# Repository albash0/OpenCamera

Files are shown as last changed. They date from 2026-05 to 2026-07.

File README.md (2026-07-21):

# OpenCamera

An open-source, mostly 3D-printed 35 mm SLR film-camera prototype controlled by an ESP32-C3.

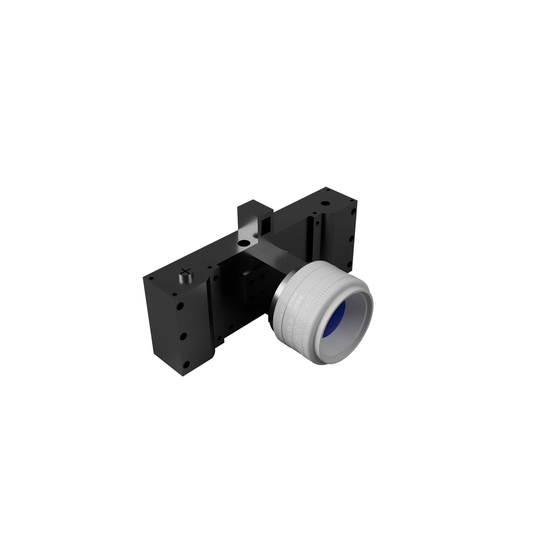
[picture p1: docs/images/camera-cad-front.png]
OpenCamera V71 CAD render


OpenCamera combines a manual 35 mm film transport with three electronically controlled systems:

- a small servo raises and lowers the SLR mirror;
- an 8520 coreless DC motor drives a rack-and-pinion shutter;
- a slot-type infrared sensor measures the shutter sweep so the ESP32-C3 can calculate the effective exposure time.

This guide describes the current **V71 prototype** represented by the CAD assembly, capstone presentation, and firmware in this repository.

> [!IMPORTANT]
> OpenCamera is a working prototype, not yet a turnkey camera kit. The repository contains one STEP assembly and working controller firmware, but it does not yet include individual STL files, a circuit schematic, a finalized PCB, a fastener list, validated slicer settings, or a film-advance counter. Expect to separate the CAD assembly into printable parts, measure hardware, adjust fits, and calibrate your build.

## Project files

| File | Purpose |
| --- | --- |
| [`camera v71.step`](camera%20v71.step) | Complete V71 mechanical assembly, including the body, film canister and roller, manual winder, mirror assembly, Canon FD flange, and servo hardware |
| [`OpenCamera_Firmware/firmware.ino`](OpenCamera_Firmware/firmware.ino) | ESP32-C3 shutter, mirror, sensor, OLED, and button controller |
| [`Capstone Presentation.pptx`](Capstone%20Presentation.pptx) | Design history, prototype photos, subsystem descriptions, and test results |

## Before you build

The current design makes several deliberate simplifications:

- **Film advance is manual.** An earlier geared-stepper design was abandoned because its electronics were too difficult to debug within the project timeline.
- **Electronics are built on protoboard.** A custom PCB was explored, but the current direct-I/O firmware no longer needs the earlier stepper circuitry.
- **The shutter has no home or end-position switch.** The firmware assumes the shutter starts at the correct end and toggles its direction flag after every trigger—even one that times out.
- **Light sealing and focus require hand fitting.** Prototype testing identified light leaks and focal-flange distance as the two main mechanical challenges.
- **The lux sensor described in the presentation is not implemented in the current firmware.** Exposure is adjusted manually by changing motor PWM.

<p align="center">
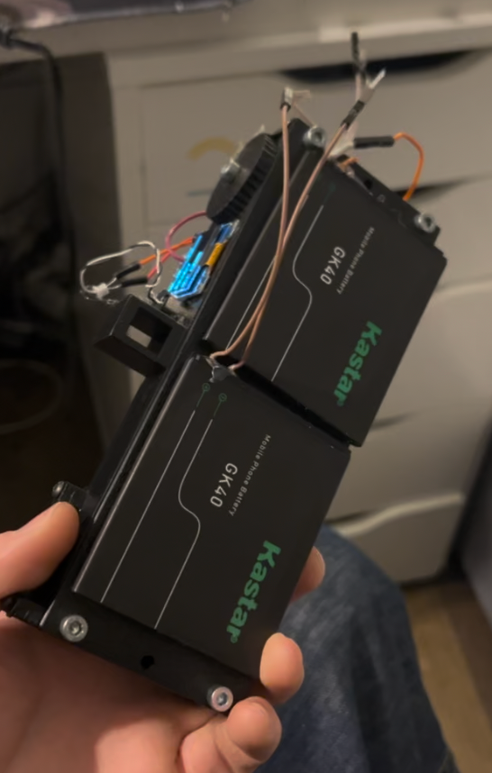
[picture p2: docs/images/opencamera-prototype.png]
OpenCamera physical prototype held in one hand
  
</p>

## How one exposure works

1. Pressing the trigger pulls its ESP32 input to ground.
2. The mirror servo moves from `40°` (viewing position) to `75°` (exposure position), then waits 250 ms.
3. The TB6612FNG drives the shutter motor at the selected PWM value. The default is `185` on a `0–255` scale.
4. The controller waits for the IR sensor to change from HIGH to LOW, records `t1`, then waits for it to return HIGH and records `t2`.
5. The motor stops, the exposure time is calculated, and the result is shown on the OLED and printed over USB serial.
6. The mirror returns to `40°`. After the exposure routine exits, the firmware toggles the direction for the next trigger.

The mirror, shutter, and sensor must all work on the bench before film is loaded.

## Parts

### Mechanical and optical parts

| Part | Notes |
| --- | --- |
| Printed V71 camera parts | Export the required bodies from the STEP assembly. The presentation recommends opaque ABS because it is durable and light resistant. |
| 35 mm film canister and take-up roller | Both are represented in the CAD assembly. The current take-up/advance mechanism is manual. |
| Canon FD lens and compatible flange | The V71 assembly includes a component named `Bague_CanonFD`. Verify focus on your printed body before exposing film. |
| Shutter panel/carriage, rack, and pinion | The shutter is designed as a removable module that screws into the camera body. |
| Laser-cut acrylic mirror | Mounted to the mirror mechanism and moved by a mini servo. A first-surface mirror will avoid the double image produced by ordinary back-silvered mirror material. |
| Translucent laminate or focusing-screen material | Mounted above the mirror so the reflected image can be viewed. |
| Light-sealing material | Opaque foam, flocking, paint, tape, or another suitable material for closing seams after fitting. |
| Shafts, screws, and small hardware | Sizes are not documented separately; inspect and measure the holes in the STEP assembly before ordering. |

### Electronics

| Part | Role |
| --- | --- |
| ESP32-C3 development board | Runs the firmware. Use a board that exposes every GPIO listed in the wiring table below. |
| TB6612FNG dual H-bridge module | Controls shutter-motor speed and direction using channel A. |
| 8520 coreless DC motor | Drives the rack-and-pinion shutter. Match its rated voltage when choosing the motor supply. |
| Slot-type IR sensor | Produces the two timing edges used to measure the shutter sweep. |
| Small RC servo | Moves the mirror. The presentation/CAD uses a mini 2 g servo; the mount may need adaptation for another servo. |
| 128×64 SSD1306 I²C OLED | Optional status display at address `0x3C`; the camera can still report over serial if it is absent. |
| 3 normally-open momentary buttons | Trigger, speed up, and speed down. The firmware uses internal pull-ups. |
| Prototyping board and hookup wire | Matches the current prototype electronics approach. |
| Suitable regulated power supplies | Size the logic, motor, and servo supplies for the actual components. Join their grounds. Never power a motor or servo from a GPIO pin. |

The presentation also mentions a boost converter, but the repository does not document the final power circuit or supply voltages. Design the power system around the ratings of your chosen board, motor, servo, sensor, and display.

### Tools and software

- a CAD program that can open STEP assemblies and export individual bodies;
- a slicer and 3D printer;
- a laser cutter or another safe method of cutting the mirror;
- soldering tools, wire cutters, and a multimeter;
- calipers for checking the film path, shutter feature, and optical spacing;
- Arduino IDE or another Arduino-compatible ESP32 build environment;
- a sacrificial or already-developed strip of 35 mm film for transport testing.

## Build guide

### 1. Inspect and separate the CAD assembly

Open [`camera v71.step`](camera%20v71.step) in your CAD program and inspect the complete mechanism before exporting anything. The assembly contains named components for the camera body, test housing, film canister, winder, film-can roller, mirror assembly, light-tight insert, Canon FD flange, and mini servo hardware.

Export only printable camera components as individual STL or 3MF files. Do not export vendor models such as the servo as printable parts. Preserve the STEP file's millimetre scale and check at least one known part before slicing.

The design is modular: the shutter is a separate unit that mounts inside the body. Keep that interface intact so the shutter can be removed for adjustment.

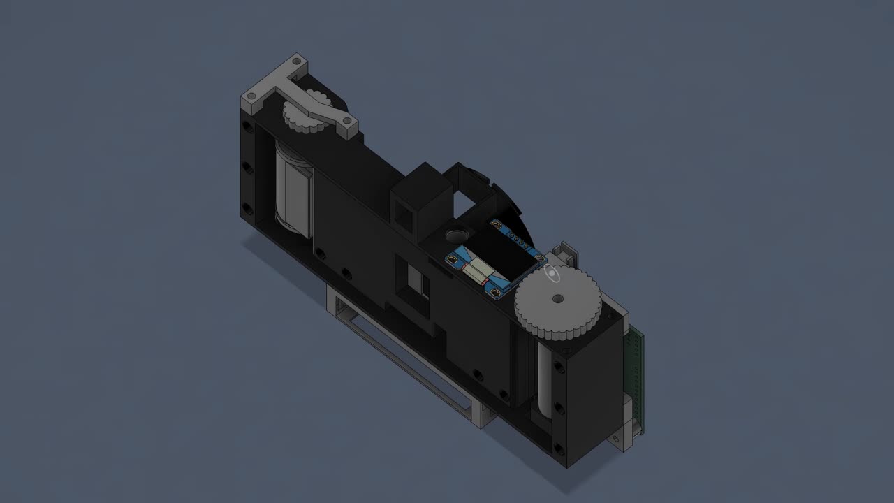
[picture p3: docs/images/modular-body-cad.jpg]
CAD render of the modular body, film path, and shutter assembly


### 2. Print and prepare the camera parts

The original build used ABS for opacity, durability, and longevity. If you use another material, hold a strong flashlight behind a test print in a dark room; a print that looks black in daylight may still leak light.

There are no validated print settings in the repository. Use the CAD geometry to choose orientation and supports, then dry-fit every moving part before final assembly. Clean the following areas carefully:

- the film rails and canister/roller pockets;
- the shutter-carriage guide and rack;
- the motor, servo, sensor, and lens-flange mounts;
- the removable shutter-module screw holes;
- the rear-cover seam and all openings into the film chamber.

Nothing in the film path should scratch emulsion, and the shutter must travel freely without binding.

### 3. Assemble the body and manual film path

1. Fit the 35 mm supply canister into its pocket.
2. Fit the take-up roller and manual winder at the opposite side.
3. Thread sacrificial film across the gate and onto the take-up roller.
4. Turn the winder slowly. Confirm that the film stays flat at the exposure gate and does not climb, buckle, or scrape.
5. Fit the rear panel and recheck the film plane. The prototype's rear panel was revised with a bulge to correct the film position and focal-flange distance.

Because the current design has no powered advance or frame counter, determine a repeatable manual advance distance with scrap film before shooting a real roll.

### 4. Build the shutter module

1. Mount the 8520 motor and pinion.
2. Install the shutter carriage so its rack meshes with the pinion without excessive pressure.
3. Move the carriage through its full stroke by hand. It must reach both ends without a tight spot.
4. Position the slot IR sensor so the shutter's timing feature passes fully through the sensor gap during each sweep.
5. Install the module in the body, but keep it accessible until calibration is complete.

The earliest shutter tests were performed as a separate bench assembly, which is the safest way to debug the motor and sensor before placing them inside a light-tight body.

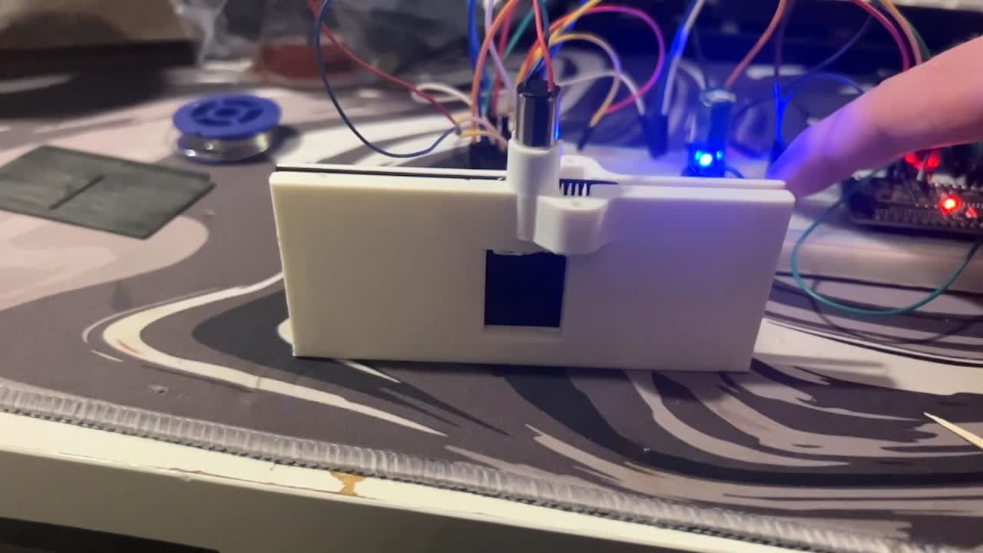
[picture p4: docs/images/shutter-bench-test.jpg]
Early shutter and sensor bench test


> [!CAUTION]
> The firmware has a short, PWM-dependent jam timeout. Always test at low mechanical load, keep fingers clear of the rack and gears, and be ready to remove power. A stalled coreless motor can heat quickly.

### 5. Assemble the SLR mirror and viewfinder

The V71 viewfinder uses a laser-cut acrylic mirror on a mini servo. With the mirror down, light from the lens is reflected upward onto a translucent laminate focusing screen. Before an exposure, the servo raises the mirror out of the film path.

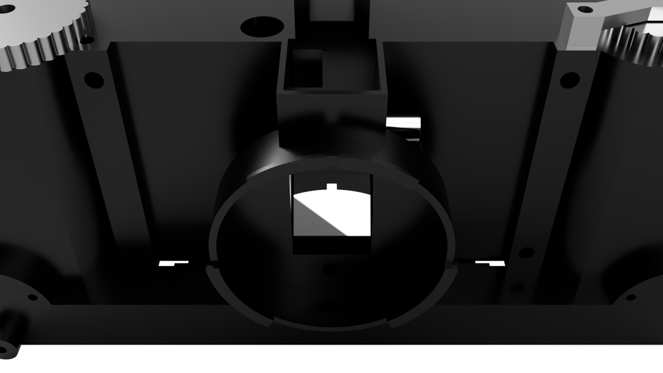
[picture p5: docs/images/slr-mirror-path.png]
CAD view through the lens mount showing the SLR mirror path


1. Attach the mirror securely to its carrier.
2. Center the servo mechanically before fitting the horn.
3. Install the servo and linkage without forcing either end of travel.
4. At the firmware's `40°` position, align the mirror so the lens image is centered on the focusing screen.
5. At `75°`, confirm that the mirror and linkage completely clear the exposure opening.
6. Adjust the horn position first; change `SERVO_DOWN` and `SERVO_UP` in firmware only for fine correction.

Servo angles are command values, not guaranteed physical angles. If the servo buzzes, stalls, or pushes against the body, disconnect it and correct the linkage or limits before continuing.

### 6. Wire the controller

The table below is taken from the actual constants in the current firmware. It replaces the older pin table that previously appeared in this README.

| ESP32-C3 GPIO | Connect to | Firmware name | Behavior |
| ---: | --- | --- | --- |
| `0` | TB6612FNG `STBY` | `STBY` | Driven HIGH to enable the motor driver |
| `1` | Mirror-servo signal | `SERVO_PIN` | 50 Hz servo control |
| `2` | TB6612FNG `PWMA` | `PWMA_PIN` | Shutter-motor PWM |
| `3` | TB6612FNG `AIN2` | `AIN2` | Motor direction |
| `4` | TB6612FNG `AIN1` | `AIN1` | Motor direction |
| `5` | Trigger button | `TRIGGER_BTN` | Active LOW; connect the other button terminal to GND |
| `6` | Speed-up button | `SPEED_UP_BTN` | Active LOW; connect the other button terminal to GND |
| `7` | Speed-down button | `SPEED_DOWN_BTN` | Active LOW; connect the other button terminal to GND |
| `8` | OLED `SDA` | — | I²C data |
| `9` | OLED `SCL` | — | I²C clock |
| `20` | IR-sensor digital output | `SENSOR_PIN` | Expected sequence during a sweep: HIGH → LOW → HIGH |

Also make these non-GPIO connections:

- connect TB6612FNG `AO1` and `AO2` to the shutter motor;
- connect TB6612FNG logic power to a compatible logic rail and `VM` to a supply appropriate for the motor;
- power the servo from a regulated supply that can handle its moving and stall current;
- power the OLED and IR module at voltages supported by their exact boards;
- connect the grounds of the ESP32-C3, motor driver, sensor, OLED, servo supply, and motor supply together.

Do not copy the layout of the prototype board blindly; use the pin table and verify every wire with a multimeter.

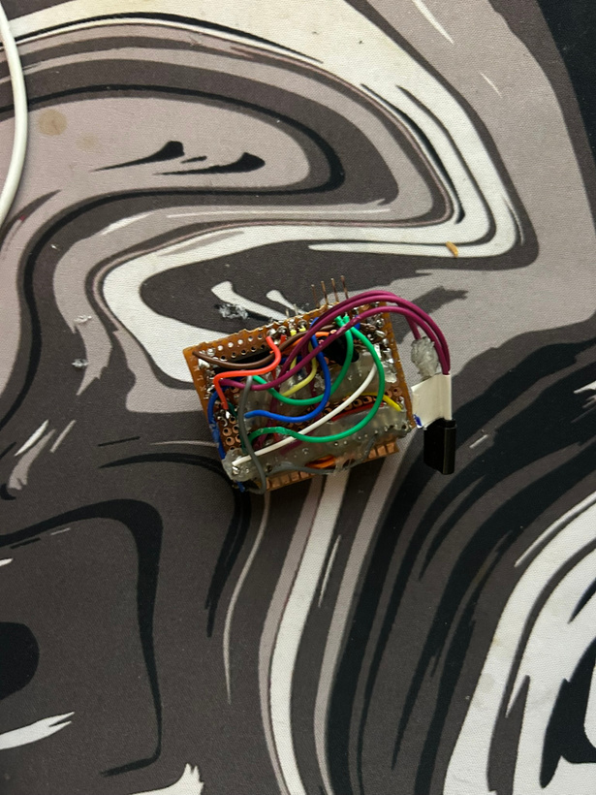
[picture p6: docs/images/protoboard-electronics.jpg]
Current direct-I/O protoboard prototype


### 7. Install and upload the firmware

Install an ESP32 board package in your Arduino-compatible environment, then install these libraries:

- **Adafruit SSD1306**
- **Adafruit GFX Library**
- **ESP32Servo**

Open [`OpenCamera_Firmware/firmware.ino`](OpenCamera_Firmware/firmware.ino), select the board definition that matches your ESP32-C3, and upload the sketch. Open the serial monitor at **115200 baud**.

On a normal start you should see messages for the OLED, servo, direct pin configuration, and `SYS_STATE: IDLE`. If no OLED is detected, the controller deliberately continues using serial output.

### 8. Perform a no-load electronics test

Disconnect the motor from the shutter rack for the first test.

1. Power the system and confirm that the mirror moves to its down position without binding.
2. Press speed up and speed down. The displayed PWM should change in steps of 5.
3. Confirm the sensor reads HIGH when clear, LOW when interrupted, and HIGH when clear again. If your module has inverted logic, the stock firmware will time out and must be adapted.
4. Tap the trigger while observing the motor direction. The next successful trigger should reverse it.
5. If the first direction would drive an installed shutter into the wrong end, swap the motor leads or correct the direction logic before coupling the rack.

The firmware does not know the shutter's absolute position. After a reset or interrupted sweep, manually return the shutter to the expected starting end and verify the commanded direction before firing again. A timed-out trigger still toggles the direction flag.

### 9. Test the complete mechanism

Couple the motor to the rack and start with the shutter module outside the camera if possible.

1. Set the carriage at the correct starting end.
2. Use a conservative PWM and fire once.
3. Confirm a clean HIGH → LOW → HIGH sensor transition.
4. Confirm the motor stops without hitting a hard end.
5. Fire again and verify that the carriage returns in the opposite direction.
6. Repeat until the movement is reliable, then install the module in the body and repeat the test.

The timeout scales from 200 ms at PWM 0 to 25 ms at PWM 255. At the default PWM of 185 it is roughly 74 ms. A mechanism that is too slow, sticky, misaligned, or not seen by the sensor will shut down before completing the cycle.

### 10. Calibrate the shutter measurement

The firmware uses two physical values:

```cpp
const float GATE_DISTANCE = 16.0; // mm represented by the measured sensor interval
const float SLIT_WIDTH    = 2.0;  // mm of the shutter opening
```

Measure both values on your finished shutter rather than assuming the defaults match your print. The firmware calculates:

```text
measured_seconds = (t2 - t1) / 1,000,000
velocity_mm_s    = GATE_DISTANCE / measured_seconds
exposure_ms      = (SLIT_WIDTH / velocity_mm_s) × 1,000
```

The serial monitor reports the result as `SHUTTER:<milliseconds>` and also prints calculated velocity and sensor-pulse duration. Compare that value with an independent shutter tester or high-frame-rate video, adjust the dimensions/PWM as needed, and repeat across several cycles. Consistency matters as much as the average value.

### 11. Set focus and make the body light-tight

Do these checks with no unprocessed film in the camera:

1. Mount the intended Canon FD lens.
2. Place translucent material temporarily at the film plane and aim at a distant, high-contrast target.
3. Adjust the lens/flange/film-plane relationship until the image focuses at both the film plane and the viewfinder screen.
4. In a dark room, put a bright light inside the empty body and inspect every seam from outside; then reverse the test by lighting the outside and inspecting the film chamber.
5. Seal the rear panel, lens-flange interface, shutter-module joint, viewfinder opening, fastener holes, and wire exits without obstructing moving parts.

Do not load fresh film until the shutter, focus, film path, and light sealing all pass independently.

### 12. Load film and shoot

1. In subdued light, load the 35 mm canister and attach the leader to the take-up roller.
2. Advance manually and verify that the film perforations and emulsion remain undamaged.
3. Close and seal the rear panel.
4. Use the speed buttons to select a calibrated motor PWM.
5. Frame and focus on the SLR screen.
6. Press the trigger once and wait for the display to return to `IDLE`.
7. Read the measured exposure time from the OLED or serial output.
8. Manually advance one frame before the next exposure.

The current firmware alternates shutter direction after each trigger; it does not advance the film automatically.

## What the controls and messages mean

| Display or serial message | Meaning |
| --- | --- |
| `PWM: 185` | Current shutter-motor command on a 0–255 scale |
| `FWD` / `REV` | Direction flag at the time of the most recent OLED refresh; after a shot it may show the completed sweep until the display updates again |
| `MIRROR UP` | Mirror is moving out of the optical path |
| `RUNNING` | Shutter motor is active |
| `SHUTTER:8.4500` | Calculated exposure time in milliseconds |
| `MIRROR DN` | Mirror is returning to the viewing position |
| `IDLE` | Exposure cycle is complete |
| `T-OUT 1` | The first expected IR transition never arrived |
| `STUCK 1` | The sensor went LOW but did not return HIGH before the timeout |

## Troubleshooting

| Problem | Check first |
| --- | --- |
| OLED is blank | Confirm address `0x3C`, SDA on GPIO 8, SCL on GPIO 9, power, and ground. Serial output should still work. |
| `T-OUT 1` | Sensor idle level, sensor alignment, shutter starting position, motor direction, rack binding, and motor power |
| `STUCK 1` | Shutter blocking the slot, sensor gap/alignment, insufficient travel, rack binding, or inverted sensor logic |
| ESP32 resets when firing | Motor/servo supply sag, inadequate regulation, missing common ground, or electrical noise |
| Motor hits an end stop | Wrong starting end or direction; there are no homing switches |
| Mirror buzzes or does not clear the gate | Servo horn alignment, linkage interference, and `SERVO_DOWN`/`SERVO_UP` limits |
| Viewfinder and film plane focus differently | Mirror angle, focusing-screen height, rear-panel/film position, and lens flange spacing |
| Fogged or streaked film | Rear-cover seam, flange, shutter-module joint, viewfinder, wire exits, or translucent print walls |
| Exposure varies from shot to shot | Sensor alignment, motor voltage, gear mesh, carriage friction, PWM, and measured calibration dimensions |

## Prototype results

The presentation documents repeated body, focus, and light-tightness revisions. The two images below are viewfinder/optical tests from the V71 stage; they are useful as evidence that the mirror path works, not as a claim that the camera is fully production-ready.

| Viewfinder test 1 | Viewfinder test 2 |
| --- | --- |
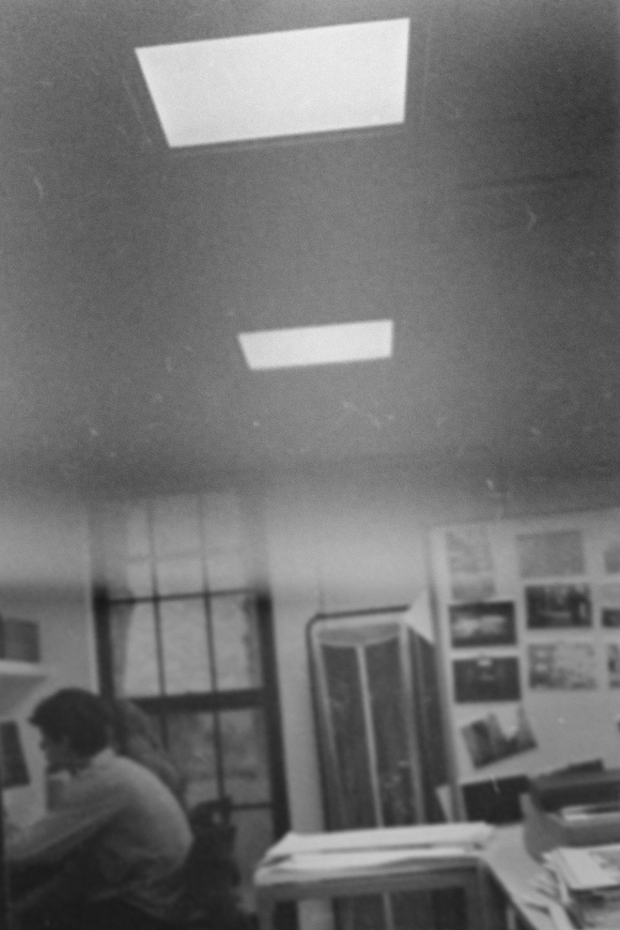
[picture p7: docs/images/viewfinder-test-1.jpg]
OpenCamera viewfinder test showing ceiling lights and a room
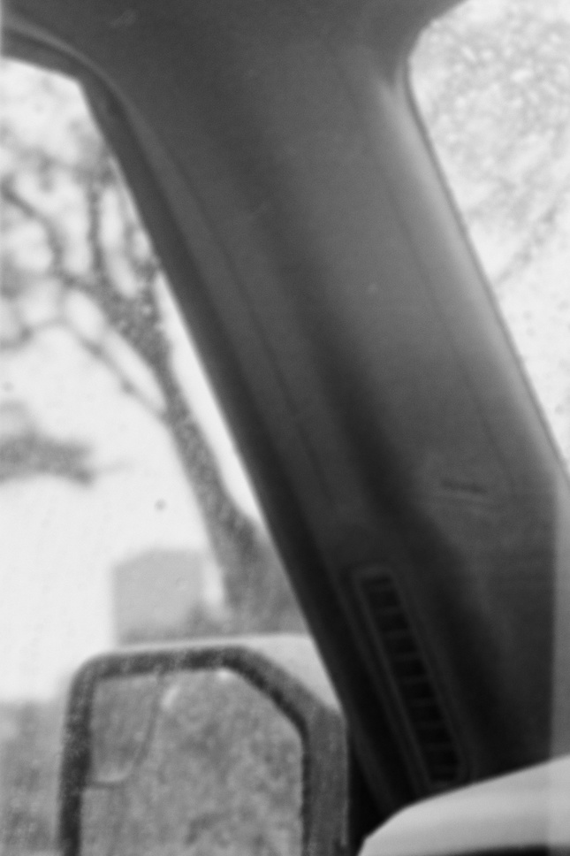
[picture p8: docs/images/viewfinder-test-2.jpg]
OpenCamera viewfinder test showing a window
|  |  |

## Known next steps

The capstone presentation identifies these remaining development goals:

- redesign the PCB for easier assembly;
- finish the external housing;
- improve light-tightness;
- add accurate, repeatable film advance.

Homing or end-position sensing would also make the bidirectional shutter safer and easier to recover after a reset.

## Contributing

Contributions are welcome, especially individual printable exports, an accurate bill of materials, a verified schematic, PCB work, light-sealing improvements, lens-mount validation, shutter calibration data, and a repeatable film-advance mechanism.

When submitting a mechanical change, state the CAD revision, print material, slicer settings, measured fit, lens mount, and test result. When submitting an electrical change, update both the firmware constants and this wiring table.

## License and image source

The repository is licensed under the [GNU General Public License v3.0](LICENSE).

Project photos and CAD renders in `docs/images/` were extracted from [`Capstone Presentation.pptx`](Capstone%20Presentation.pptx), presented by Alexander Basham at PPCDS in 2026. The original presentation remains unchanged.

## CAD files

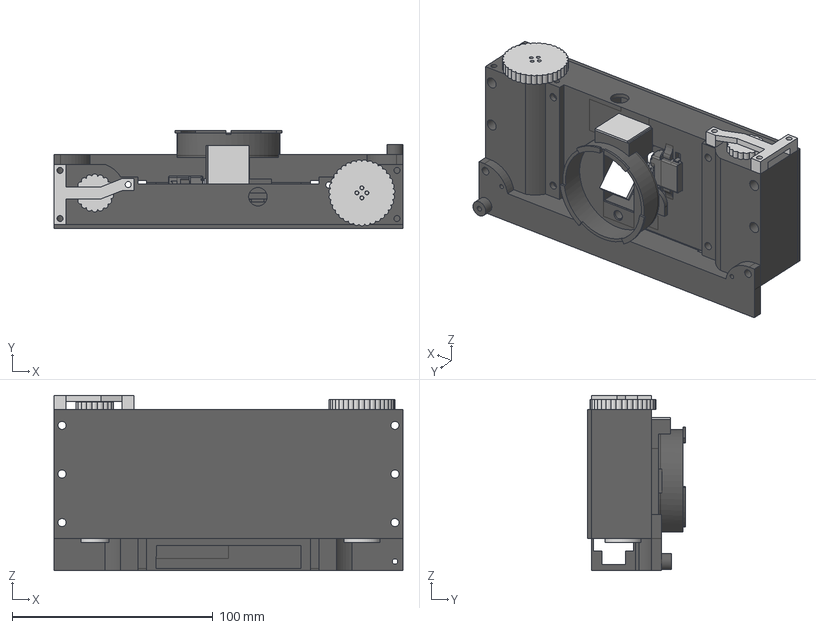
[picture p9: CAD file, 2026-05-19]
camera v71.step
174.0 x 48.9 x 87.5 mm
TestHousing
Film Cannister
hook v2(Mirror) x 2
hook v2(Mirror) (1) x 2
filmcanroller
LightTight basic (1)
Bague_CanonFD
Shaft
Horn
Screw

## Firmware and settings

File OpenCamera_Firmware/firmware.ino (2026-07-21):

#include <Arduino.h>
#include <Wire.h>
#include <Adafruit_GFX.h>
#include <Adafruit_SSD1306.h>
#include <ESP32Servo.h>

/* * PROJECT: OpenCamera (ESP32-C3)
 * VERSION: Shutter Controller (Direct Button & Servo Mirror - No PCF/No Stepper)
 * Logic: Drives rack-and-pinion shutter via TB6612FNG, controls mirror servo
 * (40° down, 75° up), measures speed via IR sensor, and reads Speed UP/DOWN 
 * buttons directly connected to GPIO 4 and 5.
 */

#define SCREEN_WIDTH 128
#define SCREEN_HEIGHT 64
#define OLED_ADDR 0x3C

Adafruit_SSD1306 display(SCREEN_WIDTH, SCREEN_HEIGHT, &Wire, -1);
Servo mirrorServo;

// --- VERIFIED PIN MAPPING (DIRECT IO VERSION) ---
const int PWMA_PIN       = 2; 
const int AIN1           = 4;  
const int AIN2           = 3;  
const int STBY           = 0;  

const int SENSOR_PIN     = 20;   // IR Feedback
const int TRIGGER_BTN    = 5;   // Shutter trigger button (GPIO 1)
const int SPEED_UP_BTN   = 6;   // Direct Speed UP button (GPIO 4)
const int SPEED_DOWN_BTN = 7;   // Direct Speed DOWN button (GPIO 5)
const int SERVO_PIN      = 1;   // Mirror Servo (GPIO 7)

// --- SERVO SETTINGS ---
const int SERVO_DOWN  = 40;  // Mirror down position
const int SERVO_UP    = 75;  // Mirror up position

// --- SETTINGS ---
int MOTOR_SPEED            = 185;    
const float GATE_DISTANCE  = 16.0;   // Distance sensor beam spans (mm)
const float SLIT_WIDTH     = 2.0;    // Physical width of shutter slit (mm)
const int RAMP_UP_DELAY    = 5;      // Initial inertia kick (ms)

unsigned long lastTriggerPress = 0;
unsigned long lastUpPress = 0;
unsigned long lastDownPress = 0;
const int DEBOUNCE_MS      = 200;

bool movingForward         = true;
float lastShutterMs        = 0.0;
bool oledDetected          = false;

// Helper to log both to Serial and optionally to OLED status line
void logSystemState(String statusMsg) {
  Serial.print("SYS_STATE: ");
  Serial.println(statusMsg);
  updateDisplay(statusMsg);
}

void updateDisplay(String statusMsg) {
  if (!oledDetected) return; 
  display.clearDisplay();
  display.setTextSize(1);
  display.setTextColor(SSD1306_WHITE);
  display.setCursor(0, 0);
  display.print("PWM: "); display.print(MOTOR_SPEED);
  display.setCursor(80, 0);
  display.print(movingForward ? "FWD" : "REV");
  display.drawFastHLine(0, 10, 128, SSD1306_WHITE);
  
  display.setTextSize(2);
  display.setCursor(0, 25);
  if (lastShutterMs > 0) {
    display.print(lastShutterMs, 2); display.print("ms");
  } else {
    display.print("READY");
  }

  display.setTextSize(1);
  display.setCursor(0, 55);
  display.print(statusMsg);
  display.display();
}

void stopMotor() {
  digitalWrite(AIN1, LOW);
  digitalWrite(AIN2, LOW);
  analogWrite(PWMA_PIN, 0);   
}

void fireShutter(bool forward) {
  // Step 1: Flip Mirror UP
  logSystemState("MIRROR UP");
  mirrorServo.write(SERVO_UP);
  delay(250); // Allow physical time for the mirror to clear the path

  logSystemState("RUNNING");
  Serial.print("FIRE_LOG: Direction=");
  Serial.print(forward ? "FORWARD" : "REVERSE");
  Serial.print(" | PWM Target=");
  Serial.println(MOTOR_SPEED);
  
  // Set Direction
  digitalWrite(AIN1, forward ? HIGH : LOW);
  digitalWrite(AIN2, forward ? LOW : HIGH);
  
  // Pulse motor
  analogWrite(PWMA_PIN, MOTOR_SPEED);
  
  unsigned long moveStartedAt = millis();
  
  // Scale timeout dynamically: higher speed (PWM 255) needs less time to complete
  // than lower speed (PWM 0). Range is constrained between 25ms and 200ms.
  long calculatedTimeout = map(MOTOR_SPEED, 0, 255, 200, 25);
  unsigned long timeout = constrain(calculatedTimeout, 25, 200);

  // Wait for shutter slit to reach sensor (Beam Blocked -> Open)
  while(digitalRead(SENSOR_PIN) == HIGH) {
    if (millis() - moveStartedAt > timeout) { 
      stopMotor(); 
      logSystemState("T-OUT 1");
      Serial.print("ERROR: Timeout waiting for shutter slit to reach sensor (Timeout: ");
      Serial.print(timeout);
      Serial.println("ms).");
      // Ensure mirror returns down in case of safety shutdown
      mirrorServo.write(SERVO_DOWN);
      return; 
    }
  }
  
  unsigned long t1 = micros(); // Slit start
  
  // Wait for slit to finish passing (Beam Open -> Blocked)
  while(digitalRead(SENSOR_PIN) == LOW) {
    if (millis() - moveStartedAt > timeout) { 
      stopMotor(); 
      logSystemState("STUCK 1");
      Serial.print("ERROR: Shutter stuck over IR beam sensor (Timeout: ");
      Serial.print(timeout);
      Serial.println("ms).");
      // Ensure mirror returns down in case of safety shutdown
      mirrorServo.write(SERVO_DOWN);
      return; 
    }
  }
  
  unsigned long t2 = micros(); // Slit end
  
  stopMotor();

  // Calculation: Time = Slit_Width / Velocity
  // Velocity = Gate_Distance / (t2 - t1)
  float durSec = (t2 - t1) / 1000000.0;
  if (durSec > 0) {
    float vel = GATE_DISTANCE / durSec;
    lastShutterMs = (SLIT_WIDTH / vel) * 1000.0;
    
    // Primary Web App / GUI compatible telemetry payload
    Serial.print("SHUTTER:"); 
    Serial.println(lastShutterMs, 4);

    // Diagnostics details
    Serial.print("DIAGNOSTICS: Velocity=");
    Serial.print(vel, 2);
    Serial.print(" mm/s | Pulse Duration=");
    Serial.print(t2 - t1);
    Serial.println(" us");
  } else {
    Serial.println("ERROR: Invalid timing calculation (durSec <= 0).");
  }

  logSystemState("DONE");

  // Step 2: Return Mirror DOWN
  delay(100); // Tiny pause before returning mirror
  logSystemState("MIRROR DN");
  mirrorServo.write(SERVO_DOWN);
  delay(250); // Allow physical time for mirror to settle down

  logSystemState("IDLE");
}

void setup() {
  Serial.begin(115200);
  
  // Let USB CDC catch up on ESP32-C3
  unsigned long startWait = millis();
  while(!Serial && millis() - startWait < 2000);

  Serial.println("\n==============================================");
  Serial.println("   OPENCAMERA SIMPLIFIED - FIRMWARE V2       ");
  Serial.println("==============================================");

  Wire.begin(8, 9); // SDA=8, SCL=9

  // Init OLED
  if(display.begin(SSD1306_SWITCHCAPVCC, OLED_ADDR)) {
    oledDetected = true;
    Serial.println("I2C_INIT: SSD1306 OLED Configured.");
  } else {
    Serial.println("I2C_INIT: OLED failed to initialize. Relying on Serial backup.");
  }

  // Setup Outputs
  pinMode(PWMA_PIN, OUTPUT);
  pinMode(AIN1, OUTPUT);
  pinMode(AIN2, OUTPUT);
  pinMode(STBY, OUTPUT);
  
  // Setup Inputs
  pinMode(SENSOR_PIN, INPUT);
  pinMode(TRIGGER_BTN, INPUT_PULLUP);
  pinMode(SPEED_UP_BTN, INPUT_PULLUP);
  pinMode(SPEED_DOWN_BTN, INPUT_PULLUP);
  
  // Servo Initialization using ESP32-specific timer allocations
  ESP32PWM::allocateTimer(0);
  ESP32PWM::allocateTimer(1);
  ESP32PWM::allocateTimer(2);
  ESP32PWM::allocateTimer(3);
  mirrorServo.setPeriodHertz(50); // Standard 50Hz servo refresh rate
  mirrorServo.attach(SERVO_PIN, 500, 2400); // Attach with standard min/max pulse widths
  mirrorServo.write(SERVO_DOWN); // Initialize with mirror in down position
  Serial.println("HARDWARE: ESP32 Servo initialized on Pin 7 (Set to 40 deg).");

  digitalWrite(STBY, HIGH); // Driver enabled
  Serial.println("HARDWARE: Direct Pin configuration complete. Standby line pulled HIGH.");

  logSystemState("IDLE");
}

void loop() {
  // 1. Physical Trigger Button
  if (digitalRead(TRIGGER_BTN) == LOW) {
    if (millis() - lastTriggerPress > DEBOUNCE_MS) {
      lastTriggerPress = millis();
      Serial.println("TRIG: Shutter button pressed.");
      fireShutter(movingForward);
      movingForward = !movingForward; // Auto-return logic
    }
  }

  // 2. Direct Speed UP Button
  if (digitalRead(SPEED_UP_BTN) == LOW) {
    if (millis() - lastUpPress > DEBOUNCE_MS) {
      lastUpPress = millis();
      int oldSpeed = MOTOR_SPEED;
      MOTOR_SPEED = min(MOTOR_SPEED + 5, 255);
      if (oldSpeed != MOTOR_SPEED) {
        Serial.print("CONFIG: Speed Incremented. Motor PWM: ");
        Serial.println(MOTOR_SPEED);
        logSystemState("ADJ SPD");
      }
    }
  }

  // 3. Direct Speed DOWN Button
  if (digitalRead(SPEED_DOWN_BTN) == LOW) {
    if (millis() - lastDownPress > DEBOUNCE_MS) {
      lastDownPress = millis();
      int oldSpeed = MOTOR_SPEED;
      MOTOR_SPEED = max(MOTOR_SPEED - 5, 0);
      if (oldSpeed != MOTOR_SPEED) {
        Serial.print("CONFIG: Speed Decremented. Motor PWM: ");
        Serial.println(MOTOR_SPEED);
        logSystemState("ADJ SPD");
      }
    }
  }
}

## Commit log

2026-05-19 uploaded v71 STEP
    [camera v71.step]
2026-07-21 Add V71 firmware and full build docs
    Adds the initial ESP32-C3 firmware sketch for the V71 prototype, including direct GPIO controls for shutter motor, mirror servo, IR timing sensor, OLED status output, and speed/trigger buttons. Rewri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
